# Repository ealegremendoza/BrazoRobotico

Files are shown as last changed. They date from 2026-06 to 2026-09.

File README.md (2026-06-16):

# Brazo robótico programable mediante ROS para automatización de tareas repetitivas basado en grabación y reproducción de trayectorias

Proyecto Final de Ingeniería Electrónica orientado al desarrollo de un brazo robótico de bajo costo para automatización de tareas repetitivas mediante grabación y reproducción de trayectorias.

El proyecto propone construir un manipulador robótico capaz de ser movido manualmente por el usuario, registrar una trayectoria y luego reproducirla de forma automática con precisión y repetibilidad. La solución se basa en ROS 2 para la lógica de control, cinemática, planificación de movimientos y futura integración con simulación en Gazebo.

## Objetivo general

Diseñar e implementar un brazo robótico programable que permita automatizar tareas simples de manipulación de objetos mediante un esquema de programación por demostración, evitando que el usuario tenga que escribir código para enseñarle una secuencia de movimientos al robot.

## Idea de funcionamiento

1. El usuario coloca el brazo en modo grabación.
2. El usuario mueve manualmente el brazo hasta las posiciones deseadas.
3. El sistema registra la trayectoria realizada.
4. El usuario selecciona una trayectoria guardada desde la interfaz física.
5. El brazo reproduce automáticamente la secuencia de movimientos.

## Alcance del proyecto

El entregable inicial contempla:

- Brazo robótico de 5 grados de libertad más pinza.
- Movimiento de objetos pequeños y livianos.
- Grabación, reproducción y borrado de trayectorias.
- Interfaz física simple mediante display y botones.
- Control de servomotores desde una computadora integrada compatible con ROS 2.
- Simulación del brazo en Gazebo para validar movimientos antes de la implementación física.
- Fabricación mediante piezas impresas en 3D, tomando como referencia el diseño SO-ARM100/SO-ARM101.

Quedan fuera del alcance inicial:

- Visión artificial.
- Detección de objetos por cámara.
- Algoritmos de inteligencia artificial.
- Navegación autónoma.
- Aplicación de escritorio para control remoto del brazo.
- Control por voz o interfaz conversacional.

## Aplicaciones previstas

El sistema está pensado para automatización ligera en entornos industriales, educativos o de laboratorio. Algunos casos de uso posibles son:

- Operaciones de pick-and-place de objetos livianos.
- Movimiento repetitivo de piezas entre posiciones predefinidas.
- Estaciones de testing electrónico.
- Demostraciones educativas de robótica, ROS 2 y cinemática de manipuladores.
- Prototipos de automatización para PyMEs donde un robot industrial de alta gama no resulta justificable.

## Arquitectura conceptual

El sistema se organiza en los siguientes bloques principales:

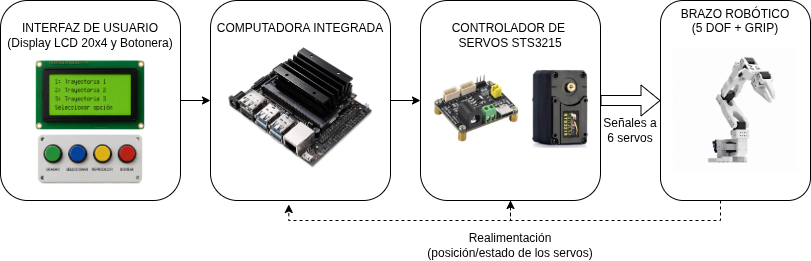
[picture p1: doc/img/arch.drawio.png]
Diagrama en bloques


## Hardware previsto

| Componente | Descripción |
|---|---|
| Brazo robótico | Basado en el proyecto SO-ARM100/SO-ARM101. |
| Estructura | Piezas impresas en 3D. Prototipado en PLA y posible versión final en PETG. |
| Actuadores | 6 servomotores STS3215: 5 DOF + pinza. |
| Controlador de servos | Placa driver compatible con servomotores STS3215. |
| Computadora integrada | A definir. Debe ser compatible con ROS 2. |
| Interfaz de usuario | Display LCD y botonera física. |
| Alimentación | A definir según consumo final de servos, computadora integrada e interfaz. |

## Software previsto

| Módulo | Función |
|---|---|
| ROS 2 | Framework principal para control y comunicación entre nodos. |
| Nodo de control del brazo | Envío de comandos hacia el controlador de servomotores. |
| Nodo de lectura de estado | Lectura de posición/estado de cada servomotor. |
| Nodo de grabación | Registro de trayectorias generadas por el usuario. |
| Nodo de reproducción | Ejecución automática de trayectorias guardadas. |
| Nodo de interfaz | Gestión de botones, display y estados del sistema. |
| Simulación Gazebo | Validación virtual del modelo y de los movimientos. |

## Requisitos funcionales principales

El brazo robótico deberá ser capaz de:

- Agarrar, levantar, sostener y trasladar objetos pequeños y livianos.
- Mover objetos desde una zona predefinida hacia otra zona predefinida.
- Permitir el encendido y apagado seguro del sistema.
- Permitir el movimiento manual del brazo durante el modo de grabación.
- Guardar trayectorias realizadas por el usuario.
- Borrar trayectorias previamente almacenadas.
- Reproducir trayectorias guardadas.
- Informar el estado del sistema mediante una interfaz simple.

## Estado actual del repositorio

Actualmente el repositorio contiene principalmente documentación del proyecto:

```text
BrazoRobotico/
└── doc/
    ├── img/          # Imágenes y diagramas del proyecto
    ├── md/           # Documentación en Markdown
    ├── pdf/          # Documentos exportados en PDF
    └── tables/       # Planillas de gestión y trazabilidad
    └── datasheets/   # Hojas de datos  
```

Archivos Markdown principales:

| Archivo | Contenido |
|---|---|
| `doc/md/agent.md` | Índice general de la documentación del proyecto. |
| `doc/md/fundamentos.md` | Idea base, alcance, motivación y funcionamiento esperado. |
| `doc/md/propuesta.md` | Propuesta aprobada por la cátedra. |
| `doc/md/proyecto-objetivos-v3.md` | Desarrollo ampliado de objetivos y alcance. |
| `doc/md/requisitos.md` | Requisitos funcionales y técnicos. |
| `doc/md/referencias.md` | Referencias de proyectos similares y brazo elegido. |
| `doc/md/materiales.md` | Materiales y componentes considerados. |
| `doc/md/modelos.md` | Modelos 3D evaluados. |
| `doc/md/cursos.md` | Recursos de aprendizaje relacionados con modelado 3D. |
| `doc/md/links.md` | Links útiles, tablero de seguimiento y bitácora. |
| `doc/md/respaldo.md` | Documento de respaldo con descripción general, FODA y desafío tecnológico. |
| `doc/md/tareas.md` | Listado de tareas tareas del proyecto. |

## Próximos pasos

- Definir computadora integrada compatible con ROS 2.
- Definir controlador de servomotores STS3215.
- Definir display, botonera y esquema de interacción con el usuario.
- Incorporar el modelo URDF/Xacro del brazo.
- Crear simulación en Gazebo.
- Implementar nodos ROS 2 para lectura de servos, grabación y reproducción de trayectorias.
- Validar el comportamiento primero en simulación y luego en el prototipo físico.
- Documentar procedimiento de instalación, calibración y operación.

## Roadmap tentativo

| Etapa | Descripción | Estado |
|---|---|---|
| Documentación inicial | Propuesta, fundamentos, requisitos y referencias. | En desarrollo |
| Selección de hardware | Servos, controlador, computadora integrada, display y fuente. | Pendiente |
| Simulación | Modelo del brazo en ROS 2/Gazebo. | Pendiente |
| Control básico | Movimiento de articulaciones desde ROS 2. | Pendiente |
| Grabación de trayectorias | Registro de posiciones y tiempos. | Pendiente |
| Reproducción automática | Ejecución de trayectorias guardadas. | Pendiente |
| Modelo mecánico | Adaptación e impresión 3D del brazo. | Pendiente |
| Integración final | Hardware, software e interfaz física. | Pendiente |

## Licencia

A definir.

## Autor
- Alumno: Ezequiel Alegre Mendoza 
- Tutores: Ing. Fernando Fiamberti, Ing. Claudia Orlandi
- Docente: Ing. Silvio Tapino
- Proyecto Final - Ingeniería Electrónica

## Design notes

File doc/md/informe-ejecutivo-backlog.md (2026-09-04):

# Informe Ejecutivo — Avance del Backlog

**Proyecto:** BrazoRobotico (brazo SO-ARM101, control ESP32 + simulación ROS2/Gazebo)
**Fecha del informe:** 2026-09-04 (primer informe)
**Fuente:** `doc/md/BACKLOG.md` y bitácoras individuales por tarea (`doc/md/bitacora-*.md`)

## Resumen general

| Categoría | Completadas | Pendientes | Total |
|---|---|---|---|
| 🔧 ESP32 / Embedded Systems | 3 (E01, E02, E05) | 5 (E03, E04, E06, E07, E08) | 8 |
| 🦾 Brazo Robótico | 2 (R01, R02) | 1 (R03) | 3 |
| **Total** | **5** | **6** | **11** |

**Avance global: 5 de 11 tareas (~45%)**, distribuidas en dos frentes independientes: comunicación serie ESP32↔Arduino (hardware/firmware) y simulación del brazo en Gazebo/ROS2 (software). Ambos frentes tienen su primera integración end-to-end funcionando.

---

## 🔧 ESP32 / Embedded Systems

### ✅ E01 — UART TX-RX en el ESP32
Implementado y validado un loopback UART2 (TX↔RX puenteados) sobre ESP-IDF/FreeRTOS en `firmware/uart_test/`. Se confirmó a nivel esquemático el módulo (ESP32-WROOM-32UE) y la elección de pines (UART2, evitando UART0 reservada para programación/monitor y UART1 por conflicto con la flash SPI). Señal validada físicamente con analizador lógico. Configuración de pines migrada de `#define` a Kconfig (`idf.py menuconfig`), quedando parametrizable sin recompilar código.

### ✅ E02 — Medición de niveles TX/RX del ESP32
Medidos los niveles lógicos reales de un GPIO de salida del ESP32 con multímetro: **0.00V (LOW) / 3.29V (HIGH)**, confirmando lógica CMOS estándar de 3.3V. Este dato fue el insumo directo para decidir en E05 que hacía falta un conversor de nivel lógico hacia el Arduino Nano (5V).

### ✅ E05 — Comunicación ESP32 ↔ Arduino Nano vía HW-221
Tarea más extensa del frente embedded. Resultado: **comunicación bidireccional validada end-to-end** — PC (monitor serie del ESP32) → ESP32 → conversor de nivel HW-221 (TXS0108E) → Arduino Nano → LED, con protocolo de framing propio (STX/FS/ETX/LRC) y ACK de vuelta por el mismo camino. Comandos "ON"/"OFF" funcionando de forma confiable en ambas direcciones.

Puntos clave resueltos en el camino:
- Identificación del chip HW-221 (marcado YF08E = TXS0108E de Texas Instruments) y su datasheet.
- Diseño y cableado del circuito completo (ver diagrama en la bitácora).
- Protocolo de framing STX/FS/ETX/LRC, reutilizable para comandos multi-campo futuros (control de servos).
- Varios bugs de firmware corregidos: máquina de estados que nunca ejecutaba su estado final, `stdin` no bloqueante del ESP32 partiendo comandos en fragmentos, lectura UART que no esperaba una línea completa.
- Un problema físico (cable TX del Nano desconectado) diagnosticado por asimetría en el comportamiento (una dirección funcionaba, la otra no).

### ⏳ Pendientes — E03, E04, E06, E07, E08
No iniciadas. Encadenadas: E03 (adaptador lógico hacia el driver de motores) y E04 (protocolo de comando del driver) habilitan E06 (traducción de comandos PC→driver en el ESP32); E07/E08 son una decisión de arquitectura (desacoplar la gestión del driver hacia el ESP32) todavía sin resolver.

---

## 🦾 Brazo Robótico

### ✅ R01 — Investigación de URDF disponible
Confirmado que el repositorio base (`TheRobotStudio/SO-ARM100`) sí provee URDF (SO100 y SO101, dos calibraciones), aunque sin paquete ROS2/Gazebo armado — solo geometría + mallas. Se vendorizó el URDF de SO101 (calibración nueva) al repo en `ros2/urdf/so101/`, quedando como base de trabajo para R02.

### ✅ R02 — Brazo funcionando en simulación Gazebo/ROS2
Tarea de mayor alcance del proyecto hasta ahora. Se armó desde cero el workspace ROS2 (`robotic_arm_ws/`) con dos paquetes:

- **`robotic_arm_description`**: URDF/xacro completo del brazo (9 links + 8 joints, límites de calibración reales), integración con `ros2_control` (`<ros2_control>` + plugin `gz_ros2_control`), launch files para visualizar en RViz y para spawnear en Gazebo Sim (Harmonic).
- **`robotic_arm_controller`**: configuración de controladores (`joint_state_broadcaster`, `arm_controller`, `gripper_controller` sobre `JointTrajectoryController`), launch para activarlos, y un nodo de control interactivo por sliders (`slider_control.py`) para mover el brazo en vivo desde una GUI.

**Resultado validado end-to-end:** el brazo se visualiza correctamente en RViz y Gazebo, `ros2_control` se activa sin errores, y se comandó y ejecutó exitosamente una trayectoria real (`Goal successfully reached!`) — el brazo responde a comandos ROS2 en simulación.

Pendiente no bloqueante: la geometría de `<collision>` usa las mismas mallas STL de detalle completo que el `<visual>`, y el motor de física de Gazebo (`dartsim`) no soporta construir colisión desde malla — confirmado con evidencia directa (log propio) y cruzado contra el proyecto de referencia del curso (mismo problema, limitación general de `dartsim`, no específica de este proyecto). El brazo hoy no tiene colisión física real en ningún link; para física realista (agarre de objetos, contacto con superficies) hace falta reemplazar esa geometría por formas primitivas (cajas/cilindros).

### ⏳ Pendiente — R03
Definir los nodos ROS2 que van a manejar el brazo robótico real (no solo simulado), basándose en el curso de referencia. Depende conceptualmente de lo armado en R02 (misma estructura de controladores aplicaría al hardware real).

---

## Próximos pasos sugeridos

1. **Frente embedded:** definir E03/E04 (adaptador lógico + protocolo del driver de motores) para desbloquear E06.
2. **Frente robótica:** R03 (nodos de control real) y, en paralelo, resolver la geometría de colisión de R02 si se necesita física realista antes de avanzar a manipulación de objetos.
3. Evaluar si conviene una tarea nueva que conecte ambos frentes (el driver de motores real controlado desde los mismos nodos ROS2 que hoy mueven la simulación).

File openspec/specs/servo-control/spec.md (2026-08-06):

# Servo Control

## Purpose

Control a 6-DOF robotic arm built with Feetech STS3215 bus servos (IDs 1-6)
from a workstation over a USB serial port (`/dev/ttyACM0`), using a desktop
GUI for commanding target positions and observing live feedback.

## Requirements

### REQ-SERVO-001: Connection lifecycle
The application opens the bus at the user-provided device path with a
baudrate of 1000000 (the STS3215 factory default), and exposes Connect and
Disconnect actions that are mutually exclusive. While disconnected, all
servo controls are disabled.

#### Scenario: Connect to the bus
- **Given** servos 1 and 2 are powered and on the bus at `/dev/ttyACM0`
- **When** the user enters `/dev/ttyACM0` and clicks Connect
- **Then** the port opens, the baudrate is set to 1000000, and per-servo
  status is polled every 100 ms
- **And** Connect becomes disabled while Disconnect becomes enabled

#### Scenario: Disconnect
- **When** the user clicks Disconnect while connected
- **Then** the port is closed, all sliders are disabled, and all servos are
  shown as disconnected

### REQ-SERVO-002: Per-servo command with limits
Each servo has one horizontal slider and Min/Max inputs beside it. Changing
Min/Max re-ranges that slider, clamped to the servo's native 0-4095 count
range (12-bit position). A centered label above the slider shows the current
commanded position.

#### Scenario: Re-range a slider
- **Given** the slider of servo 1 ranges from 0 to 4095
- **When** the user sets Min=1000 and Max=2000
- **Then** the slider re-ranges to 1000-2000 and any out-of-range current
  value is clamped into the new range

### REQ-SERVO-003: Per-servo status from sync read
Servo connectivity and feedback are derived per servo from
`GroupSyncRead.isAvailable(id, ...)`, never from the global
`txRxPacket()` result, which reports `COMM_RX_CORRUPT` whenever any id in
the group is missing.

#### Scenario: Only two of six servos connected
- **Given** only servos 1 and 2 are on the bus
- **When** a sync read cycle completes
- **Then** servos 1 and 2 are marked Connected with live position and
  velocity feedback and enabled sliders
- **And** servos 3-6 are marked Disconnected with disabled sliders

### REQ-SERVO-004: Feedback display
To the right of each slider the UI shows the read position (raw counts), the
read velocity (signed via `scs_tohost(value, 15)`), and the
connected/disconnected state, color-coded.

### REQ-SERVO-005: Write behaviour
Slider movement writes the goal position with debounce (40 ms coalescing)
plus an immediate flush on mouse release, using `WritePosEx(id, position,
speed=2400, acc=50)`. The write is skipped for a servo whose last poll
marked it disconnected.

## Design

- **GUI**: tkinter/ttk single-window, one `ServoRow` frame per servo.
- **Bus reads**: one `GroupSyncRead(packetHandler, SMS_STS_PRESENT_POSITION_L, 4)`
  covers position (56-57) and speed (58-59) for all six ids in a single
  transaction; `scs_tohost(speed_raw, 15)` restores the sign.
- **Bus writes**: single-servo `WritePosEx` per changed slider.
- **Polling**: a 100 ms `after()` loop drives feedback; a failed serial
  operation triggers disconnect instead of crashing the UI.
- **Errors**: SDK failures are `COMM_*` return codes, never exceptions; the
  UI surfaces connect/open failures as a status label.
- **Entry point**: `STServo_Python/servo_control_ui.py` adds
  `stservo-env/` to `sys.path` so `scservo_sdk` imports from any cwd.

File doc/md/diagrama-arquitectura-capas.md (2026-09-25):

# Arquitectura por capas

```mermaid
flowchart TB
    subgraph L7[7 - Aplicacion]
        SUP[arm_supervisor]
        REC[recording_manager]
        TS[task_server]
        UI[RViz / consola Linux - opcional]
    end

    subgraph L6[6 - Planificacion de movimiento - MoveIt2]
        MG[move_group]
        MPY[MoveItPy]
    end

    subgraph L5[5 - Control - ros2_control]
        JTC[arm_controller y gripper_controller]
        JSB[joint_state_broadcaster]
        RSP[robot_state_publisher]
    end

    subgraph L4[4 - Interfaz de hardware]
        PLUGIN[RoboticArmInterface - plugin C++]
    end

    subgraph L3[3 - Comunicacion]
        UART[UART 115200 - tramas M, E, S, D]
    end

    subgraph L2[2 - Firmware ESP32]
        FW[Estados, parada de emergencia, torque, display]
    end

    subgraph L1[1 - Hardware]
        SERVOS[Servos STS3215]
        PANEL[Botonera, LCD 20x4, potenciometro]
    end

    TS --> MPY
    UI --> MG
    MG --> JTC
    MPY --> JTC
    JTC --> PLUGIN
    PLUGIN --> UART
    UART --> FW
    FW --> SERVOS
    FW --> PANEL
```

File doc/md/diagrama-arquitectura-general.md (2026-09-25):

# Arquitectura general

```mermaid
flowchart TB
    USER([Usuario])

    subgraph HW[Brazo robotico]
        PANEL[Botonera, LCD y potenciometro]
        ESP[ESP32 - seguridad y control de servos]
        SERVOS[Servos STS3215]
    end

    subgraph PC[Computadora integrada - ROS 2]
        APP[Aplicacion - supervisor, grabaciones y tareas]
        MOTION[Planificacion de movimiento - MoveIt2]
        CTRL[Control - ros2_control]
    end

    USER --> PANEL
    USER -.->|opcional| APP
    PANEL --> ESP
    ESP --> SERVOS
    ESP -->|UART - protocolo propio| CTRL
    CTRL --> ESP
    CTRL -->|eventos de botones| APP
    APP --> MOTION
    MOTION --> CTRL
```

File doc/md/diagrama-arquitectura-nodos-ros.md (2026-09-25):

# Nodos, topics, actions y servicios ROS 2

```mermaid
flowchart LR
    subgraph CM[controller_manager]
        PLUGIN[RoboticArmInterface - hardware plugin]
        JSB[joint_state_broadcaster]
        ARM[arm_controller]
        GRIP[gripper_controller]
    end
    RSP[robot_state_publisher]
    MG[move_group]
    RVIZ[rviz2 - opcional use_rviz]
    TS[task_server - MoveItPy]
    SUP[arm_supervisor]
    REC[recording_manager]
    ESP[ESP32 - UART M E S D]

    T_JS(["/joint_states"])
    T_RD(["/robot_description"])
    T_TF(["/tf"])
    T_EV(["/esp32/events"])
    T_ST(["/esp32/start"])
    T_DI(["/esp32/display"])
    T_SS(["/arm_supervisor/state"])

    A_ARM[["/arm_controller/follow_joint_trajectory"]]
    A_GRIP[["/gripper_controller/follow_joint_trajectory"]]
    A_MOVE[["/move_action"]]
    A_TASK[["/task_server"]]

    S_REC{{"save, list, get, delete"}}

    ESP -->|serial| PLUGIN
    PLUGIN -->|serial| ESP

    JSB --> T_JS
    T_JS --> RSP
    T_JS --> MG
    T_JS --> TS
    RSP --> T_RD
    RSP --> T_TF
    T_TF --> RVIZ

    RVIZ --> A_MOVE
    A_MOVE --> MG
    MG --> A_ARM
    MG --> A_GRIP
    TS --> A_ARM
    TS --> A_GRIP
    A_ARM --> ARM
    A_GRIP --> GRIP

    PLUGIN -.-> T_EV
    T_EV -.-> SUP
    SUP -.-> T_ST
    T_ST -.-> PLUGIN
    SUP -.-> T_DI
    T_DI -.-> PLUGIN
    SUP -.-> T_SS
    T_SS -.-> TS

    SUP -.->|home, ejecutar grabacion| A_TASK
    A_TASK --> TS
    SUP -.->|cancelar ante parada| A_ARM
    SUP -.-> S_REC
    S_REC -.-> REC

    classDef planned stroke-dasharray: 5 5
    class SUP,REC,T_EV,T_ST,T_DI,T_SS,S_REC planned
```

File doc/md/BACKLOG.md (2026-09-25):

# Backlog de Tareas

_Última actualización: 2026-09-25_

## Cómo usar este documento
- Agregar tareas nuevas bajo la categoría correspondiente (o crear una nueva sección si hace falta).
- Marcar como hecha cambiando `[ ]` por `[x]`.
- Mover tareas completadas a la sección "Hecho" si querés mantener el backlog activo limpio.

---

## 🔧 ESP32 / Embedded Systems

- [x] **[E01]** Programar ESP32 para poder enviar y recibir mensajes por puerto serie a través de los pines TX-RX
- [x] **[E02]** Medir niveles de las señales que salen por TX y RX del ESP32 usando el analizador lógico
- [x] **[E03]** Averiguar si es necesario un adaptador lógico entre el ESP32 y el driver de los servomotores; si se necesita, conseguir uno — ver `doc/md/bitacora-E03-adaptador-logico.md` (no hace falta, ambos son 3.3V)
- [x] **[E04]** Averiguar cómo comandar el driver de motores vía TX-RX — ver `doc/md/bitacora-E04-protocolo-driver.md` (protocolo Feetech/Dynamixel-like, header 0xFF 0xFF + ID + length + instrucción + parámetros + checksum)
- [x] **[E05]** Probar el código del ESP32 para manejar TX-RX con un Arduino Nano; programar el Arduino Nano para que pueda enviar y recibir mensajes por los pines TX-RX
- [ ] **[E06]** (Depende de E01) Hacer un código en el ESP32 que traduzca los comandos recibidos de la computadora principal en los comandos que precisa el driver de los motores; estudiar el código Python de ejemplo
- [ ] **[E07]** Evaluar si hace falta realmente desacoplar la gestión del driver de motores hacia el ESP32, o si está bien como está
- [ ] **[E08]** (Depende de E07) Hacer un nuevo script de Python para delegar la parte de gestión del driver de motores al ESP32

## 🦾 Brazo Robótico

- [x] **[R01]** Averiguar si el proyecto armso-101 (en el cual está basado mi proyecto) tiene un URDF para simular con Gazebo ROS2 — ver `doc/md/bitacora-R01-urdf.md`
- [x] **[R02]** (Depende de R01) Si tiene URDF: tratar de levantar el modelo en Gazebo. Si no tiene: ver cómo generarlo usando los STL disponibles — ver `doc/md/bitacora-R02-gazebo.md`. Pendiente no bloqueante: geometría de `<collision>` (STL → primitivas, `dartsim` no soporta colisión desde malla)
- [ ] **[R03]** Definir la arquitectura ROS2 de la aplicación: paquetes, nodos, interfaces entre ellos (topics, servicios, actions) y diferencias entre simulación y robot real, tomando como base el curso de manipuladores con ROS2
- [ ] **[R04]** Investigar/implementar mitigación de backlash mecánico de los servos STS3215 (compensación por software al invertir dirección, ya que el encoder está en el eje del motor y no en el eslabón de salida)
- [x] **[R05]** Implementar MoveIt2 para planificación de movimiento del brazo — referencia: `/home/ezequiel/cursos/Robotics-and-ROS2-Manipulators/Robotics-and-ROS-2-Learn-by-Doing-Manipulators/Section6_Kinematics/arduinobot_ws` — ver `doc/md/bitacora-R05-moveit2.md`. Plan & Execute verificado end-to-end en Gazebo (grupos `arm` y `gripper`)
- [x] **[R06]** Aprender el manejo de Actions en ROS2 (goal/result/feedback, action server y client, patrón Future) — referencia: ejemplo Fibonacci en `/home/ezequiel/cursos/Robotics-and-ROS2-Manipulators/Robotics-and-ROS-2-Learn-by-Doing-Manipulators/Section7_Application/arduinobot_ws` — ver `doc/md/bitacora-R06-actions.md`
- [x] **[R07]** (Depende de R05, R06) Implementar API para manejar MoveIt2 (interfaz programática para enviar goals de planificación/ejecución al brazo, en vez de operarlo solo desde RViz) — ver `doc/md/bitacora-R07-moveit-api.md`. `task_server` verificado end-to-end en Gazebo (tareas 0-6)
- [ ] **[R08]** (Depende de R07) Ejecutar el `task_server`/API de MoveIt2 sobre el brazo real — recalibrar o verificar que el "0" físico de los servos coincida con el "0" del modelo URDF antes de correr goals planificados en hardware
- [ ] **[R09]** (Depende de R05) Implementar en C++ el plugin `ros2_control` (`hardware_interface::SystemInterface`) para el brazo real — comunicación directa por puerto serie reusando la lógica de `STServo_Python`, dejando la interfaz reemplazable más adelante por una variante con ESP32 (ver `[E07]`)
- [x] **[R10]** Crear los nodos `simple_serial_transmitter` y `simple_serial_receiver` en Python (topic ↔ puerto serie) igual que en el curso — referencia: `/home/ezequiel/cursos/Robotics-and-ROS2-Manipulators/Robotics-and-ROS-2-Learn-by-Doing-Manipulators/Section9_Build/arduinobot_ws/src/arduinobot_firmware/arduinobot_firmware` — ver `doc/md/bitacora-R10-serial-nodes.md`
- [x] **[R11]** Estudiar cómo funciona un lifecycle node (managed node) en ROS2 — ver `doc/md/bitacora-R11-lifecycle-node.md`
- [x] **[R12]** Crear el paquete `robotic_arm_bringup` con `simulated_robot.launch.py` y `real_robot.launch.py`, que incluyan los launch de description (solo sim), controller, moveit y remote pasándoles `is_sim` — referencia: `/home/ezequiel/cursos/Robotics-and-ROS2-Manipulators/Robotics-and-ROS-2-Learn-by-Doing-Manipulators/Section9_Build/arduinobot_ws/src/arduinobot_bringup` — ver `doc/md/bitacora-R12-bringup.md`. Simulado verificado end-to-end (RViz + `task_server`); `real_robot.launch.py` sin probar hasta `[E06]`

## 📌 Otros

- [ ] (agregar tareas aquí)

---

## ✅ Hecho

- [x] (ejemplo de tarea completada)

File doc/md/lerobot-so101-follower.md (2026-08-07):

# LeRobot — Brazo SO-101 Follower: control y calibración

Documento de profundización técnica sobre el subsistema *follower* del brazo SO-101 en
LeRobot (HuggingFace), enfocado en su **control** y su **calibración**. Todo el contenido
fue verificado contra el código fuente del repositorio local de LeRobot (rutas listadas en
[Referencias](#7-referencias)); cuando un dato no pudo confirmarse se indica explícitamente.

---

## 1. Resumen y contexto

LeRobot es el framework de código abierto de HuggingFace para *robot learning*: unifica
grabación de demostraciones, entrenamiento de políticas y teleoperación sobre hardware real.
Su ecosistema de brazos de bajo costo (diseñados por TheRobotStudio, familias SO-ARM100 /
SO-ARM101) incluye el brazo **SO-101**, usado como brazos *leader* (guía) y *follower*
(ejecutor).

El brazo **SO-101 follower** tiene 5 grados de libertad más una pinza (gripper). Los 6 ejes
usan servos **Feetech STS3215** con reductora 1/345 y resolución de encoder de 12 bits
(4096 cuentas por vuelta). El *leader* del SO-101 usa en cambio motorizaciones mixtas
(1/191, 1/345, 1/147 según el eje) para poder sostenerse y moverse a mano.

Para el proyecto **BrazoRobotico** (ROS 2 + grabación/reproducción de trayectorias sobre
servos Feetech ST) este subsistema es la referencia de cómo LeRobot resuelve los problemas
reales de un brazo de bajo costo:

- **Calibración**: encontrar el cero físico (`homing_offset`), el rango mecánico
  (`range_min`/`range_max`) y persistirlo de forma consistente.
- **Control**: un bucle de teleoperación pasivo que lee posiciones, normaliza valores y
  escribe objetivos de posición con protecciones de seguridad (clip de acción, límites de
  torque en la pinza).

---

## 2. Arquitectura del subsistema

La clase base es `SOFollower(Robot)` en
`src/lerobot/robots/so_follower/so_follower.py` (242 líneas):

```python
class SOFollower(Robot):
    config_class = SOFollowerRobotConfig
    name = "so_follower"
```

- **Alias `SO100Follower` y `SO101Follower`**: ambos son la misma clase
  (`SO100Follower = SOFollower` y `SO101Follower = SOFollower` al final del archivo). La
  distinción entre SO-100 y SO-101 es solo cosmética desde el punto de vista del código.
- **Registro de configuración**: `SOFollowerRobotConfig` se registra con dos claves mediante
  `@RobotConfig.register_subclass`:
  - `"so101_follower"`
  - `"so100_follower"`
  - El atributo `name` de la instancia queda en `"so_follower"` (sin versión), lo cual
    condiciona la ruta del archivo de calibración (ver [Ruta del JSON](#42-ruta-del-json-y-estructura)).
- **Factory**: `make_robot_from_config(config)` en `src/lerobot/robots/utils.py` despacha
  `"so100_follower"` → `SO100Follower` y `"so101_follower"` → `SO101Follower`. En
  `__init__` el bus se arma con 6 motores `sts3215`:

  | Nombre | ID | Modo de normalización |
  | ------ | -- | --------------------- |
  | `shoulder_pan` | 1 | `DEGREES` (o `RANGE_M100_100` si `use_degrees=False`) |
  | `shoulder_lift` | 2 | ídem |
  | `elbow_flex` | 3 | ídem |
  | `wrist_flex` | 4 | ídem |
  | `wrist_roll` | 5 | ídem |
  | `gripper` | 6 | `RANGE_0_100` (siempre) |

- **Bimanual**: `BiSOFollower` (`src/lerobot/robots/bi_so_follower/bi_so_follower.py`)
  compone dos instancias de `SOFollower` (`left_arm`/`right_arm`), registrado como
  `"bi_so_follower"`. Cada brazo mantiene su propio bus, puerto y calibración.

---

## 3. Control del brazo follower

### 3.1 Ciclo de vida

El flujo típico (usado por los scripts y por el contexto manager `with robot:`):

```
connect()  →  calibrate() (si aplica)  →  configure()
→  get_observation() / send_action()  (bucle)
→  disconnect()
```

Detalles de cada etapa:

- `connect(calibrate=True)` (so_follower.py:92):
  1. `bus.connect()` → abre el puerto serie y hace el *handshake* (ver [Protocolo Feetech](#38-protocolo-feetech)).
  2. Si `not is_calibrated and calibrate`: invoca `calibrate()` (recalibración interactiva o
     reescritura desde archivo, ver [Calibración](#4-calibración-en-profundidad)).
  3. Conecta las cámaras.
  4. Llama `configure()`.
  - El docstring advierte: se asume que en el momento de conectar **el brazo está en
    reposo** (posición de reposo), porque el torque puede deshabilitarse de forma segura
    para correr la calibración.
- `get_observation()` → `sync_read` de `Present_Position` + captura de cámaras.
- `send_action(action)` → escribe `Goal_Position` por `sync_write` con clip de seguridad.
- `disconnect()` → `bus.disconnect(disable_torque_on_disconnect)` + desconexión de cámaras.
  Si `disable_torque_on_disconnect=True` (valor por defecto), se deshabilita el torque antes
  de cerrar el puerto para evitar que los motores queden aplicando torque de resistencia.

`Robot` (`src/lerobot/robots/robot.py`) aporta la infraestructura base: `_load_calibration`
/ `_save_calibration`, `calibration_dir`, `calibration_fpath` y el context manager
(`__enter__` conecta, `__exit__` desconecta incluso con error). También define las
propiedades abstractas `observation_features` y `action_features` que describen la estructura
plana de observaciones/acciones: claves `"<motor>.pos"` y, para las cámaras, la clave de
cámara (más `"<cam>_depth"` si usa profundidad).

### 3.2 Configuración clave

`SOFollowerConfig` (`config_so_follower.py`, 64 líneas) — hereda de `RobotConfig` (que
aporta `id`, `calibration_dir`):

| Campo | Valor por defecto | Significado |
| ----- | --- | --- |
| `port` | — (obligatorio) | Puerto serie del bus (p. ej. `/dev/ttyACM0`) |
| `disable_torque_on_disconnect` | `True` | Deshabilita torque al desconectar |
| `max_relative_target` | `None` | Límite máximo de la acción relativa; `float` (todos los motores) o `dict[str, float]` por motor |
| `cameras` | `{}` | Configuración de cámaras (`CameraConfig`) |
| `use_degrees` | `True` | `True` → normalización `DEGREES`; `False` → `RANGE_M100_100` |
| `position_p_coefficient` | `16` | Ganancia P del PID de posición |
| `position_i_coefficient` | `0` | Ganancia I |
| `position_d_coefficient` | `32` | Ganancia D |
| `num_read_retries` | `2` | Reintentos adicionales de `sync_read` ante paquetes corruptos |

`SOFollowerRobotConfig` es la unión de `RobotConfig` + `SOFollowerConfig` (sin campos
adicionales), con los alias `SO100FollowerConfig`/`SO101FollowerConfig`.

### 3.3 Normalización de valores

El bus normaliza automáticamente los registros `Goal_Position` y `Present_Position`
(única lista `NORMALIZED_DATA = ["Goal_Position", "Present_Position"]` en feetech.py:47).
La normalización exige calibración cargada: sin `calibration`, `_normalize`/`_unnormalize`
lanzan `RuntimeError`.

El modo de normalización se define por motor en el `MotorNormMode`
(`src/lerobot/motors/motors_bus.py:169`):

- **`DEGREES`** (cuerpo, cuando `use_degrees=True`). Lectura normalizada:

  ```
  mid   = (range_min + range_max) / 2
  max_res = resolution - 1          # = 4095 para STS3215
  norm  = (raw - mid) * 360 / max_res
  ```

  Es decir, la posición central (`mid`) reporta `0°` y el rango mecánico completo abarca
  ±180°. La escritura inversa es `raw = int(val * max_res / 360 + mid)`.

- **`RANGE_0_100`** (pinza). Normaliza a porcentaje:

  ```
  norm = ((raw - range_min) / (range_max - range_min)) * 100
  ```

  Para la pinza, **`100` = abierta** (en `range_max`) y `0` = cerrada (en `range_min`). Con
  `drive_mode=1` se invierte (`norm = 100 - norm`).

- **`RANGE_M100_100`** (cuerpo cuando `use_degrees=False`): normaliza al rango [-100, 100]
  con `norm = ((raw - min) / (max - min)) * 200 - 100`, negando el signo si `drive_mode=1`.

  > Detalle: `DEGREES` **ignora** `drive_mode`; los modos `RANGE_*` sí lo aplican. En la
  > calibración del follower siempre se escribe `drive_mode=0`, por lo que la inversión
  > solo es relevante si un JSON trae `drive_mode=1` (caso típico de brazos *leader* con
  > ejes montados invertidos).

Los valores crudos leídos/escritos se convierten siempre al espacio normalizado cuando el
registro está en `NORMALIZED_DATA`, tanto en `sync_read`/`sync_write` como en `read`/`write`
(con el flag `normalize`).

### 3.4 `configure()`

`SOFollower.configure()` (so_follower.py:159) se ejecuta bajo el context manager
`bus.torque_disabled()` (garantiza re-habilitar torque al final):

1. `bus.configure_motors()` (feetech.py:209), para cada motor:
   - `Return_Delay_Time = 0` (reduce el retardo de respuesta de los 500 µs por defecto al
     mínimo de 2 µs).
   - `Maximum_Acceleration = 254` y `Acceleration = 254` (solo protocolo 0 para el primero)
     para acelerar el arranque y frenado.
   - **Limpieza del bit 4 (0x10) del registro `Phase` (0x12)** en los `sts3215`: fuerza el
     modo de realimentación de ángulo a 0, manteniendo las lecturas en `[0, resolution-1]`
     y evitando valores negativos o desbordados.
2. Por motor:
   - `Operating_Mode = OperatingMode.POSITION.value` (= 0, modo servo de posición).
   - `P_Coefficient = 16`, `I_Coefficient = 0`, `D_Coefficient = 32` (desde config).
3. **Límites de seguridad de la pinza** (`gripper`), para evitar quemar el motor:
   - `Max_Torque_Limit = 500` (50 % del torque máximo).
   - `Protection_Current = 250` (50 % de la corriente máxima).
   - `Overload_Torque = 25` (25 % de torque al detectar sobrecarga).

### 3.5 `send_action()`

`SOFollower.send_action(action)` (so_follower.py:204) devuelve **la acción realmente
enviada** (posiblemente recortada), que puede diferir de la original:

1. Extrae de `action` las claves que terminan en `.pos` como `goal_pos` por motor.
2. **Clip por `max_relative_target`**: si está configurado, primero hace un
   `sync_read("Present_Position")` adicional y luego
   `ensure_safe_goal_position(goal_present_pos, max_relative_target)`
   (`src/lerobot/robots/utils.py:91`), que recorta el delta `goal - present` al rango
   `[±max_relative_target]` por motor. El propio código advierte: `Slower fps expected due
   to reading from the follower.` — ese `sync_read` extra encarece el bucle.
3. Escribe `Goal_Position` en todos los motores con un único `sync_write`.
4. Devuelve el dict `{f"{motor}.pos": val}` con los valores efectivamente escritos.

### 3.6 `get_observation()`

`SOFollower.get_observation()` (so_follower.py:179):

1. `bus.sync_read("Present_Position", num_retry=config.num_read_retries)` → un
   `GroupSyncRead` de los 6 motores (valores normalizados). Se convierte a claves
   `"<motor>.pos"`.
2. Por cada cámara: `read_latest()` (RGB) y opcionalmente `read_latest_depth()` (clave
   `"<cam>_depth"`).

### 3.7 El follower es pasivo: el bucle vive en el script

`SOFollower` **no tiene** `teleop_step` ni un bucle propio: es un dispositivo pasivo
que solo responde a llamadas. El bucle de control está en
`src/lerobot/scripts/lerobot_teleoperate.py` (`teleop_loop`, fps por defecto **60**):

```python
obs = robot.get_observation()                       # 1. observación
raw_action = teleop.get_action()                    # 2. acción del teleoperador
teleop_action = teleop_action_processor((raw_action, obs))
robot_action_to_send = robot_action_processor((teleop_action, obs))
_ = robot.send_action(robot_action_to_send)         # 3. enviar al follower
```

El mismo patrón de `get_observation` → `get_action` → procesadores → `send_action` es el
que usa el pipeline de grabación de datasets. `lerobot_find_joint_limits.py` usa un bucle
idéntico (ver [CLI](#45-cli)).

### 3.8 Protocolo Feetech

Detalles del bus `FeetechMotorsBus` (`src/lerobot/motors/feetech/feetech.py`, 459 líneas) y
sus tablas (`src/lerobot/motors/feetech/tables.py`, 257 líneas):

- **Comunicación**: puerto serie USB + SDK `feetech-servo-sdk` (`scservo_sdk`, basado en el
  SDK Dynamixel), protocolo **v0**, baudrate por defecto **1 Mbaud**
  (`DEFAULT_BAUDRATE = 1_000_000`), timeout de paquete 1000 ms. En la tabla de baudrates,
  1 Mbaud corresponde al valor `0` del registro `Baud_Rate`.
- **Handshake** (`_handshake`): dos verificaciones en `connect()`:
  1. `_assert_motors_exist()`: `ping` a cada ID esperado y comprobación del número de
     modelo (`sts3215` → 777). Si falta un ID o el modelo no coincide, lanza `RuntimeError`
     con la lista de motores esperados/encontrados.
  2. `_assert_same_firmware()`: lee `Firmware_Major_Version` (addr 0) y `Firmware_Minor_Version`
     (addr 1) de todos los motores; si no son iguales, lanza `RuntimeError` indicando que hay
     que actualizar el firmware con el software de Feetech.
- **Monkeypatch `setPacketTimeout`**: el SDK publicado en PyPI tiene un bug en el cálculo
  del timeout de paquete (issue IBY2S6 de Gitee, ya corregido en el repo oficial de Feetech
  pero no publicado). LeRobot lo parchea en runtime:
  `packet_timeout = (tx_time_per_byte * packet_length) + (tx_time_per_byte * 3.0) + 50`.
- **Registro `Phase` (0x12), bit 4 (0x10)**: se limpia en `configure_motors()` para los
  `sts3215` (ver [3.4](#34-configure)); solo se sabe necesario para ese modelo.
- **Lectura/escritura en grupo**: `GroupSyncRead`/`GroupSyncWrite` del SDK para
  `sync_read`/`sync_write`; `broadcast_ping` para escaneo. Nota: `sync_write` no espera
  paquete de estado (puede perder paquetes) pero es rápido; `write` sí espera respuesta
  (más lento, para configuración).
- **Paquetes corruptos**: los buses Feetech devuelven ocasionalmente un paquete de estado
  corrupto (`"Incorrect status packet!"`), sobre todo cuando varios ejes se mueven a la vez.
  Por eso `num_read_retries` (por defecto 2) reintenta de inmediato (sin `sleep`) solo ante
  fallo; el costo de lectura en estado estable no cambia.
- **Torque**: `disable_torque()` escribe `Torque_Enable = 0` **y** `Lock = 0`;
  `enable_torque()` escribe `Torque_Enable = 1` **y** `Lock = 1`. El registro `Lock`
  (addr 55) desbloquea/bloquea el EEPROM, condición necesaria para escribir la
  calibración (ver [Calibración](#4-calibración-en-profundidad)).
- **Encoding sign-magnitude, bit 15**: los registros de posición/velocidad/carga usan
  *sign-magnitude* (bit de signo = dirección). Para STS, `Goal_Position`, `Present_Position`,
  `Goal_Velocity`, `Present_Velocity`, `Goal_Speed`, `Present_Speed` y `Present_Load` usan el
  bit de signo 15; `Homing_Offset` usa el bit 11. `encode_sign_magnitude` pone el bit de
  signo en 1 si el valor es negativo: `value = (dir << sign_bit) | magnitude`, con magnitud
  máxima `(1 << sign_bit) - 1`.
- **Resolución**: 4096 ticks por vuelta (12 bits) para `sts3215`; `max_res = 4095`.

---

## 4. Calibración en profundidad

### 4.1 Qué es la calibración

Para cada motor, `MotorCalibration` (`motors_bus.py:175`) define 5 campos:

| Campo | Descripción |
| ----- | --- |
| `id` | ID en el bus (1..6) |
| `drive_mode` | Dirección/inversión del motor (0 = normal). En el follower siempre 0 |
| `homing_offset` | Desplazamiento de cero físico. Convención Feetech: `Present_Position = Actual_Position - Homing_Offset` |
| `range_min` | Límite inferior del rango mecánico (cuentas de encoder) |
| `range_max` | Límite superior del rango mecánico |

La calibración existe porque el STS3215 **no tiene un "reset" de posición**: la posición
reportada (0-4095) es una lectura de encoder y el cero físico depende de cómo se montó el
horn del servo. Es la misma motivación del script propio
`STServo_Python/calibrate_servo_offset.py` (ver [Relevancia](#5-relevancia-para-el-proyecto-brazorobotico)).

### 4.2 Doble persistencia

La calibración vive en **dos lugares** que deben coincidir:

1. **EEPROM del motor** (memoria no volátil del servo), vía `write_calibration`
   (feetech.py:268). Con protocolo 0 escribe:
   - `Homing_Offset` (addr 31, 2 bytes)
   - `Min_Position_Limit` (addr 9, 2 bytes)
   - `Max_Position_Limit` (addr 11, 2 bytes)
2. **Archivo JSON** en el host, vía `_save_calibration` (`Robot` en robot.py:162).

`is_calibrated` (feetech.py:227) compara ambos: `read_calibration()` lee de los motores
`Min_Position_Limit`, `Max_Position_Limit` y (protocolo 0) `Homing_Offset`, y verifica que
el conjunto de motores y los rangos (y offsets, en protocolo 0) coincidan con
`self.calibration` (cargado del JSON). Con protocolo 1 los offsets no se comparan.

### 4.3 Ruta del JSON y estructura

Ruta (robot.py:49-56):

```python
self.calibration_dir  = config.calibration_dir or HF_LEROBOT_CALIBRATION / ROBOTS / self.name
self.calibration_fpath = self.calibration_dir / f"{self.id}.json"
```

- `HF_LEROBOT_CALIBRATION` = variable de entorno `HF_LEROBOT_CALIBRATION`, o por defecto
  `~/.cache/huggingface/lerobot/calibration` (deriva de `HF_LEROBOT_HOME`, no de
  `LEROBOT_HOME`, que está deprecado).
- `ROBOTS = "robots"` (constantes.py:45).
- **OJO**: la carpeta usa `self.name = "so_follower"`, **no** `so101`. La ruta completa
  efectiva es:

  ```
  ~/.cache/huggingface/lerobot/calibration/robots/so_follower/<id>.json
  ```

  (o `$HF_LEROBOT_CALIBRATION/robots/so_follower/<id>.json` si se define la variable).
- El JSON se carga/guarda con `draccus` (`config_type("json")`). Estructura efectiva de
  `dict[str, MotorCalibration]`:

  ```json
  {
    "shoulder_pan": {
      "id": 1,
      "drive_mode": 0,
      "homing_offset": -1947,
      "range_min": 91,
      "range_max": 4031
    },
    "shoulder_lift": { "id": 2, "drive_mode": 0, "homing_offset": -16, "range_min": 27, "range_max": 3981 },
    "elbow_flex":   { "id": 3, "drive_mode": 0, "homing_offset": 291, "range_min": 128, "range_max": 3798 },
    "wrist_flex":   { "id": 4, "drive_mode": 0, "homing_offset": 1932, "range_min": 50, "range_max": 3985 },
    "wrist_roll":   { "id": 5, "drive_mode": 0, "homing_offset": 250, "range_min": 0, "range_max": 4095 },
    "gripper":      { "id": 6, "drive_mode": 0, "homing_offset": -281, "range_min": 156, "range_max": 4043 }
  }
  ```

  (los valores numéricos son ilustrativos; solo los nombres de clave, IDs y campos son
  canónicos del formato).

### 4.4 Flujo de `SOFollower.calibrate()`

`SOFollower.calibrate()` (so_follower.py:115):

1. **¿Existe archivo de calibración?** Si `self.calibration` ya está cargado (el JSON del
   id existe), pregunta al usuario:

   ```
   Press ENTER to use provided calibration file associated with the id <id>, or type 'c' and press ENTER to run calibration:
   ```

   - `ENTER` → escribe la calibración del archivo a los motores
     (`bus.write_calibration(self.calibration)`) y termina.
   - `'c'` → continúa con calibración nueva.

2. **Preparación**: `bus.disable_torque()` (desbloquea EEPROM vía `Lock=0`) y escribe
   `Operating_Mode = POSITION` en todos los motores.

3. **Homing (cero físico)**: pide al usuario

   ```
   Move <robot> to the middle of its range of motion and press ENTER....
   ```

   y ejecuta `set_half_turn_homings()` (motors_bus.py:775), que:
   - `reset_calibration()`: escribe `Homing_Offset = 0`, `Min_Position_Limit = 0` y
     `Max_Position_Limit = max_res` (= 4095).
   - Lee `Present_Position` crudo de cada motor.
   - Calcula el offset de medio giro: `homing_offset = pos - int(max_res / 2)`
     (= `pos - 2047` en STS3215), de modo que la posición actual pase a reportar
     exactamente 2047 (el punto medio del encoder).
   - Escribe `Homing_Offset` por motor.

4. **Registro de rangos de movimiento** (`record_ranges_of_motion`, motors_bus.py:803),
   con excepción de `wrist_roll`:

   ```
   Move all joints except 'wrist_roll' sequentially through their entire ranges of motion.
   Recording positions. Press ENTER to stop...
   ```

   Con el torque deshabilitado, el método lee `Present_Position` en bucle, actualiza
   min/max de cada motor y muestra una tabla `NAME | MIN | POS | MAX` en vivo, hasta que se
   presiona Enter. Lanza `ValueError` si algún motor quedó con min == max (no se movió).
   Tras la grabación, `wrist_roll` se fuerza a `range_min = 0`, `range_max = 4095`
   (es un eje de giro continuo de vuelta completa).

5. **Persistencia**: construye el dict `MotorCalibration` con `drive_mode=0`, y:
   - `bus.write_calibration(self.calibration)` → escribe `Homing_Offset`,
     `Min_Position_Limit`, `Max_Position_Limit` en el EEPROM de cada motor.
   - `self._save_calibration()` → guarda el JSON en `calibration_fpath`.
   - Imprime `Calibration saved to <ruta>`.

### 4.5 CLI

**`lerobot-calibrate`** (`src/lerobot/scripts/lerobot_calibrate.py`, 110 líneas):

```bash
lerobot-calibrate \
    --robot.type=so101_follower \
    --robot.port=/dev/ttyACM0 \
    --robot.id=my_follower
```

- Requiere exactamente uno de `--teleop.*` o `--robot.*` (el `__post_init__` lanza
  `ValueError` si ambos o ninguno).
- Elige dispositivo con `make_robot_from_config` / `make_teleoperator_from_config`,
  conecta con `connect(calibrate=False)` (sin auto-calibración), ejecuta
  `device.calibrate()` y desconecta en `finally`.

**`lerobot-find-joint-limits`** (`lerobot_find_joint_limits.py`, 227 líneas): con
teleoperación, ejecuta un bucle de control (teleop → `send_action` → `get_observation`) y
aplica **cinemática directa** desde un URDF para medir los límites de las articulaciones y
los límites del efector final:

```bash
lerobot-find-joint-limits \
  --robot.type=so100_follower --robot.port=<port> --robot.id=black \
  --teleop.type=so100_leader --teleop.port=<port> --teleop.id=blue \
  --urdf_path=<ruta>/so101_new_calib.urdf \
  --target_frame_name=gripper \
  --teleop_time_s=30 --warmup_time_s=5 --control_loop_fps=30
```

- Fases: *warmup* (5 s sin registrar) y *recording* (30 s moviendo cada articulación a sus
  topes); imprime `max_ee`/`min_ee` (x, y, z) y `max_pos`/`min_pos` (radianes).
- El URDF recomendado es `Simulation/SO101/so101_new_calib.urdf` del repo
  TheRobotStudio/SO-ARM100.

**`lerobot-setup-motors`** (asociado, documentado en so101.mdx): asigna ID y baudrate a
cada motor en el EEPROM, conectando el controlador a **un solo motor a la vez**, fuera del
daisy-chain (ver [Particularidades](#47-particularidades)).

### 4.6 `is_calibrated` y desajuste en `connect()`

Al conectar, si no hay archivo de calibración o el archivo no coincide con los motores
(`is_calibrated` falso), `connect()` llama automáticamente a `calibrate()`, que despliega
la elección interactiva ENTER / 'c' descrita arriba. Esto permite:

- **Primera vez**: sin JSON → calibración completa (homing + rangos).
- **Cambio de firmware/reset de motores**: el desajuste de rangos/offsets dispara el
  diálogo; se puede restaurar desde el archivo (ENTER) o recalibrar ('c').

### 4.7 Particularidades

- **`wrist_roll` (id 5)**: rango forzado `[0, 4095]` en la calibración (giro completo).
- **Gripper (id 6)**: normalización `RANGE_0_100` y límites de seguridad especiales en
  `configure()` (ver [3.4](#34-configure)); el calibrado de su rango es igual al resto
  (homing + rangos), pero al ser una pinza el rango registrado corresponde a la apertura
  física, y `100` = abierta.
- **Espejo 1:1 entre leader y follower**: la calibración debe coincidir entre ambos brazos
  para que, en la misma posición física, reporten los mismos valores (esto es lo que permite
  que una política entrenada en un brazo funcione en otro, y que la teleoperación sea un
  mapeo directo).
- **`setup_motors()`** (so_follower.py:173): itera los motores en **orden inverso**
  (empieza por el `gripper`, id 6). Por cada uno pide conectar el controlador **solo a ese
  motor** y ejecuta `bus.setup_motor(motor)`, que escanea baudrate/ID (protocolo 0:
  `broadcast_ping`), deshabilita torque, escribe el ID destino y el `Baud_Rate` de 1 Mbaud
  en el EEPROM, y reconfigura el bus. Los motores nuevos vienen con ID 1; esta etapa es
  obligatoria una vez antes de armar el brazo.
- **Cámaras y observaciones**: la calibración de motores es independiente de las cámaras;
  el JSON solo contiene los 6 `MotorCalibration`.

### 4.8 Errores comunes

| Error / síntoma | Causa y tratamiento |
| --- | --- |
| `Some Motors use different firmware versions` | Firmware no uniforme entre los 6 motores (`_assert_same_firmware`). Actualizar con el software de Feetech. |
| `Missing motor IDs` / `Motors with incorrect model numbers` | El `ping` del handshake no encontró un ID o el modelo no es `sts3215` (777). Revisar cableado, daisy-chain, alimentación y `--port`. |
| `Could not connect on port ...` (`ConnectionError`) | Puerto incorrecto o permisos; probar `lerobot-find-port` y, en Linux, `sudo chmod 666 /dev/ttyACM0`. |
| `Incorrect status packet!` | Paquete de estado corrupto en el `sync_read` (típico con varios ejes en movimiento). Mitigado por `num_read_retries` (2 por defecto). |
| Lecturas fuera de `[0, 4095]` o negativas | Bit 4 del registro `Phase` (0x12) activo; se limpia en `configure_motors()` para `sts3215`. |
| `connect()` calibra de forma inesperada | `connect()` asume el brazo en reposo y auto-calibra si `is_calibrated` es falso; usar `connect(calibrate=False)` para controlar el momento. |

---

## 5. Relevancia para el proyecto BrazoRobotico

El proyecto propio opera sobre el mismo hardware (bus Feetech STS3215, `scservo_sdk`) y ya
tiene dos herramientas en `STServo_Python/`:

- **`calibrate_servo_offset.py`** (194 líneas): calibra el cero (`OFS`, registro 31-32) y los
  límites de recorrido de **un servo a la vez**, por CLI. Detalles de implementación:
  desbloquea el EEPROM con `unLockEprom`, escribe offset (sign-magnitude con **bit de signo 11**,
  rango [−2047, 2047] según el datasheet `ST3215 memory register map`, addr 0x1F "Position
  correction") con `--target`/`--reset`, escribe límites con `--min`/`--max`, re-bloquea con
  `LockEprom` y verifica. Convención unificada con LeRobot:
  `Present_Position = Actual_Position - Homing_Offset (mod 4096)`. OJO: el signo y el bit son
  los de Feetech (bit 11); usar el bit 15 (convención de `Goal_Position`) rompe el homing
  (fue el bug detectado en la primera corrida real de `calibrate-arm.py`).
- **`servo_control_ui.py`** (449 líneas): GUI Tkinter con 6 sliders para comandar posición
  de los servos 1..6 sobre el bus (1 Mbaud, `/dev/ttyACM0`), con lectura de
  `Present_Position`/`Present_Speed` por `GroupSyncRead` en un hilo de fondo
  (`ServoBusWorker`), escrituras limitadas en tasa y cola thread-safe.

**Conceptos de LeRobot directamente aplicables al brazo propio:**

1. **Homing offset y límites** — la misma idea de `calibrate_servo_offset.py`; LeRobot
   agrega la calibración *por brazo completo* y persistida en JSON, que es la base para
   reproducibilidad entre sesiones.
2. **Normalización** — los modos `DEGREES`/`RANGE_0_100`/`RANGE_M100_100` son el puente
   entre cuentas de encoder crudas y unidades físicas (grados / porcentaje de apertura).
   Aplicar esta capa evita que la lógica de control dependa del montaje mecánico.
3. **PID y límites de seguridad** — ganancias P=16 / I=0 / D=32 y, sobre todo, los topes de
   torque/corriente/sobrecarga de la pinza son un patrón de seguridad que el proyecto propio
   puede replicar en el control de trayectorias (ROS 2).
4. **Bucle pasivo** — el follower de LeRobot es un dispositivo sin bucle propio; el control
   (frecuencia, procesado, clipping) vive fuera. Es una separación limpia que encaja con el
   diseño de un nodo de control en ROS 2.
5. **`max_relative_target`** — recorte de la acción relativa por seguridad; equivalente a
   una limitación de velocidad en el espacio de articulaciones.

---

## 6. Tabla de referencia rápida

**IDs y normalización de motores** (`SOFollower.__init__`):

| Motor | ID | Modelo | Norm mode |
| ----- | -- | --- | --- |
| `shoulder_pan` | 1 | `sts3215` | `DEGREES` (o `RANGE_M100_100`) |
| `shoulder_lift` | 2 | `sts3215` | ídem |
| `elbow_flex` | 3 | `sts3215` | ídem |
| `wrist_flex` | 4 | `sts3215` | ídem |
| `wrist_roll` | 5 | `sts3215` | ídem |
| `gripper` | 6 | `sts3215` | `RANGE_0_100` |

**Registros clave de la tabla de control STS3215** (`STS_SMS_SERIES_CONTROL_TABLE`):

| Registro | Dirección | Tamaño | Nota |
| --- | --- | --- | ---- |
| `Firmware_Major_Version` | 0 | 1 | solo lectura |
| `Firmware_Minor_Version` | 1 | 1 | solo lectura |
| `Model_Number` | 3 | 2 | solo lectura; STS3215 = 777 |
| `ID` | 5 | 1 | EEPROM |
| `Baud_Rate` | 6 | 1 | 1 Mbaud = 0 |
| `Min_Position_Limit` | 9 | 2 | EEPROM |
| `Max_Position_Limit` | 11 | 2 | EEPROM |
| `Max_Torque_Limit` | 16 | 2 | EEPROM (gripper = 500) |
| `Phase` | 18 | 1 | bit 4 (0x10) se limpia |
| `P_Coefficient` | 21 | 1 | EEPROM (16) |
| `D_Coefficient` | 22 | 1 | EEPROM (32) |
| `I_Coefficient` | 23 | 1 | EEPROM (0) |
| `Protection_Current` | 28 | 2 | gripper = 250 |
| `Homing_Offset` | 31 | 2 | EEPROM; sign-magnitude bit 11 |
| `Operating_Mode` | 33 | 1 | POSITION = 0 |
| `Overload_Torque` | 36 | 1 | gripper = 25 |
| `Torque_Enable` | 40 | 1 | SRAM |
| `Acceleration` | 41 | 1 | SRAM |
| `Goal_Position` | 42 | 2 | SRAM; sign-magnitude bit 15 |
| `Lock` | 55 | 1 | 0 = desbloquea EEPROM |
| `Present_Position` | 56 | 2 | solo lectura; sign-magnitude bit 15 |
| `Maximum_Acceleration` | 85 | 1 | fábrica (254) |

**Comandos CLI**:

| Comando | Uso |
| --- | --- |
| `lerobot-calibrate --robot.type=so101_follower --robot.port=<port> --robot.id=<id>` | Calibración del follower |
| `lerobot-find-joint-limits ... --urdf_path=<urdf> --target_frame_name=gripper` | Límites de articulación y efector |
| `lerobot-setup-motors --robot.type=so101_follower --robot.port=<port>` | IDs y baudrate (un motor a la vez) |
| `lerobot-teleoperate --robot.type=so101_follower ... --teleop.type=so101_leader ...` | Bucle de teleoperación |

**Rutas**:

| Elemento | Ruta |
| --- | ---- |
| JSON de calibración | `~/.cache/huggingface/lerobot/calibration/robots/so_follower/<id>.json` (o `$HF_LEROBOT_CALIBRATION/...`) |
| Clase del follower | `lerobot/src/lerobot/robots/so_follower/so_follower.py` |
| Config del follower | `lerobot/src/lerobot/robots/so_follower/config_so_follower.py` |
| Clase base `Robot` | `lerobot/src/lerobot/robots/robot.py` |
| Bus de motores (normalización, calibración a nivel bus) | `lerobot/src/lerobot/motors/motors_bus.py` |
| Driver Feetech | `lerobot/src/lerobot/motors/feetech/feetech.py` |
| Tablas de control STS/SCS | `lerobot/src/lerobot/motors/feetech/tables.py` |
| CLI de calibración | `lerobot/src/lerobot/scripts/lerobot_calibrate.py` |
| CLI de límites | `lerobot/src/lerobot/scripts/lerobot_find_joint_limits.py` |
| Guía oficial SO-101 | `lerobot/docs/source/so101.mdx` |

---

## 7. Referencias

Repositorio LeRobot local (`/home/ezequiel/proyecto-final/lerobot`):

- `src/lerobot/robots/so_follower/so_follower.py` — `SOFollower`, aliases, ciclo de vida,
  `calibrate()`, `configure()`, `get_observation()`, `send_action()`.
- `src/lerobot/robots/so_follower/config_so_follower.py` — `SOFollowerConfig`,
  `SOFollowerRobotConfig`, registro `so101_follower`/`so100_follower`.
- `src/lerobot/robots/robot.py` — clase base `Robot`, persistencia de calibración.
- `src/lerobot/robots/utils.py` — `make_robot_from_config`, `ensure_safe_goal_position`.
- `src/lerobot/robots/bi_so_follower/bi_so_follower.py` — `BiSOFollower`.
- `src/lerobot/motors/motors_bus.py` — `MotorCalibration`, `MotorNormMode`, `_normalize`/
  `_unnormalize`, `set_half_turn_homings`, `record_ranges_of_motion`, `sync_read`/`sync_write`,
  torque.
- `src/lerobot/motors/feetech/feetech.py` — `FeetechMotorsBus`, handshake, monkeypatch,
  calibración a nivel bus, torque.
- `src/lerobot/motors/feetech/tables.py` — tablas de control, baudrates, resolución,
  encoding.
- `src/lerobot/motors/encoding_utils.py` — `encode/decode_sign_magnitude`.
- `src/lerobot/utils/constants.py` — `HF_LEROBOT_CALIBRATION`, `ROBOTS`.
- `src/lerobot/scripts/lerobot_calibrate.py`, `lerobot_find_joint_limits.py`,
  `lerobot_teleoperate.py`.
- `docs/source/so101.mdx` — guía oficial de armado, setup de motores y calibración.

Proyecto BrazoRobotico (`/home/ezequiel/proyecto-final/BrazoRobotico`):

- `STServo_Python/calibrate_servo_offset.py` — calibración de offset/límites por servo.
- `STServo_Python/servo_control_ui.py` — GUI de control de posición de 6 servos.

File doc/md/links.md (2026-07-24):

# Links útiles
## Herramientas de seguimiento
- Usare un tablero kanban en JIRA para hacer el seguimiento de mis tareas. 
    - Link al tablero: https://ealegremendoza.atlassian.net/jira/software/projects/KAN/boards/1

- Voy llevando una bitácora en el archivo del siguiente link.
    - Link: https://docs.google.com/document/d/15SSJkKiB1PeQPN0kVh5Vpq75p_l4SLlW58fwhfUnh_U/edit?usp=drive_link

- Repositorio para compartir archivos con los docentes.
    - Link: https://frbautneduar-my.sharepoint.com/:f:/g/personal/stapino_frba_utn_edu_ar/IgBXhhozbZdMSYAqC1IhuUROAWqo8cG5XLlbY5q3OoX4uok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
    
## Referencias de otros proyectos similares
Los siguientes links deben tomarse como referencias para el proyecto.
Ver referencias.md

## ESP32
- [ESP32 WROOM 32](https://www.espboards.dev/esp32/esp32-wroom/)
- [Getting Started with the ESP32 Development Board](https://randomnerdtutorials.com/getting-started-with-esp32/)
- [ESP32 Dev board Pinout, Specifications, datasheet and Schematic](https://www.etechnophiles.com/esp32-dev-board-pinout-specifications-datasheet-and-schematic/#power-pins)

## Robotica
- [Robot Learning: A Tutorial](https://huggingface.co/spaces/lerobot/robot-learning-tutorial)
- [lerobot github repository](https://github.com/huggingface/lerobot)
- [lerobot assembly tutorial](https://huggingface.co/docs/lerobot/so101)
- [LeRobot SO-ARM101 Robotic Arm - Assembly and Setup Guide\](https://www.youtube.com/watch?v=70GuJf2jbYk)
- [SO101 Arms: Calibration and Motor Configuration](https://www.youtube.com/watch?v=Nhfda8h7e2I)

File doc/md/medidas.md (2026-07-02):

# Medidas
## Servo STS3215
|id|real(mm)|simulación(mm)|simulación(101%)(mm)|
|---|---|---|---|
|a|31.8|31.8|32.118|
|b|24.7|24.7|24.947|
|c|18.44|18.4|18.584|
|d|14|14|14.14|
|e|45.48|||
|f|29|||
|g|33|||
|h||||
|i||||
|j||||
|k||||
|l|35|||
|m||||
|dGear|5.7|||
|dPlastic|6|||

|i||||
|j||||
|k||||
|l|35|||
|m||||
|dGear|5.7|||
|dPlastic|6|||

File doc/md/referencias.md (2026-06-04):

# Referencias

## Proyectos similares
Los siguientes links deben tomarse como referencias para el proyecto.

- Brazo Robótico (KUKA inspired): Diseño y Ensamblaje Completo. https://www.youtube.com/watch?v=ixrZgr7dIdw
    - 4 DOF + grip
    - Solo que usa Matlab como UI, yo no estoy pensando usar una aplicación de escritorio. 
    - Tampoco usa ROS, solamente envia ordenes de movimiento a los servomotores. 
    - Pero ejemplifica lo que quiero hacer. 
    
- Construí un Brazo Robótico (Inspirado en KUKA) desde cero!. https://www.youtube.com/watch?v=D84KoitsC-o
    - 4 DOF + grip
    - Me gusta más el diseño.
    - Solo que usa Matlab como UI, yo no estoy pensando usar una aplicación de escritorio. 
    - Tampoco usa ROS, solamente envia ordenes de movimiento a los servomotores. 
    - Pero ejemplifica lo que quiero hacer. 
    
- Brazo robótico con Arduino - Robotic Arm - Guardar/Reproducir/Exportar/Importar Movimientos. https://www.youtube.com/watch?v=1b1YxPmp97I
    - 5 DOF +grip
    - Solo que usa Matlab como UI, yo no estoy pensando usar una aplicación de escritorio. 
    - Tampoco usa ROS, solamente envia ordenes de movimiento a los servomotores. 
    - Pero ejemplifica lo que quiero hacer. 
    - El proveedor provee archivos formato STEP para hacer modificaciones.
    
- Testing of Feetech STS3215 Servomotor: Backlash, Repeatability, and Torque
    - Link https://robonine.com/testing-of-feetech-sts3215-servomotor-backlash-repeatability-and-torque/
    
## Brazo robótico elegido
- Realizaré el brazo robótico que se muestra en el proyecto SO-ARM100.
    - Video ejemplo: https://www.youtube.com/watch?v=nyuowI5lGRw
    - Imagen de referencia del brazo robótico (voy a construir el blanco):  https://www.hiwonder.com/products/lerobot-so-101?variant=42198960177239#gallery-10
    - Repositorio del proyecto (incluye los archivos para impresión 3D): https://github.com/TheRobotStudio/SO-ARM100/tree/main/Simulation
    - Información sobre el servo STS3215: https://robonine.com/testing-of-feetech-sts3215-servomotor-backlash-repeatability-and-torque/

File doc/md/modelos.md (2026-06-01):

# Modelos 3D de brazos robóticos para imprimir
- Este modelo es una sola pieza. Es para decoración. https://www.printables.com/model/1405519-kuka-based-robotic-arm-replica

- Este modelo es solamente una visualización del brazo KUKA en 3D. https://sketchfab.com/3d-models/robotic-arm-kuka-0211a7f80bdc48f784af6796913af96b

- 4DOF Robotic Arm (KUKA Inspired). Precio $4mil. https://cults3d.com/en/3d-model/gadget/4dof-kuka-inspired-robotic-arm

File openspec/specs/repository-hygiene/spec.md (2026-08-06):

# Repository Hygiene

## Purpose

Keep the git repository free of machine-local and regenerable artifacts, so
clones stay small and portable.

## Requirements

### REQ-HYG-001: Never commit the virtualenv
The Python virtualenv under `STServo_Python/stservo-env/` is regenerable via
`requirements.txt` and machine-specific (absolute paths, platform wheels).
It is ignored by `.gitignore` and must never be tracked.

#### Scenario: A new clone
- **Given** a fresh clone of the repository
- **When** the developer creates `STServo_Python/stservo-env` with
  `python -m venv` and installs `STServo_Python/requirements.txt`
- **Then** the working tree matches the tracked files with no venv bloat

### REQ-HYG-002: .gitignore only affects untracked files
Ignore rules have no effect on already-tracked files. If a file was
committed before its ignore rule existed, it must be removed from the index
with `git rm --cached` (keeping it on disk), then committed.

#### Scenario: A tracked file matches an ignore rule
- **Given** `.vscode/browse.vc.db*` was committed before being added to
  `.gitignore`
- **When** `git rm --cached` is run on those files and committed
- **Then** the files stay on disk but stop appearing as modified

### REQ-HYG-003: Ignored content in this repository
The `.gitignore` ignores `STServo_Python/stservo-env/`, `**/__pycache__/`,
`.vscode/browse.vc.db*`, and `.atl/` (local tooling cache).

## Design

- Tracked Python entry points live outside the venv (e.g.
  `STServo_Python/servo_control_ui.py`), importing the SDK from
  `stservo-env/` via a `sys.path` insert.
- Use `git check-ignore -v <path>` to verify why a path is ignored and
  `git check-ignore --no-index` to test rules against tracked paths.

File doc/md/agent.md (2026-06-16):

# Titulo del proyecto
Brazo robótico programable mediante ROS para automatización de tareas repetitivas basado en grabación y reproducción de trayectorias.

## Fundamentos
Ver idea base, y fundamentos en el archivo fundamentos.md

## Documentación de respaldo
Ver documentación de respaldo del proyecto en respald.md

## Propuesta de proyecto
La propuesta fue basada en lo descrito en fundamentos.md
Ver propuesta de proyecto aprobada por la catedra en el archivo propuesta.md

## Herramienta de seguimiento
Ver links.md
    
## Requisitos
Ver requisitos del proyecto en el archivo requisitos.md

## Referencias del proyecto
Ver referencias.md

## Tareas
Ver tareas del proyecto en tareas.md

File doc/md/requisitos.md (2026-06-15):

# Requisitos del proyecto

## Título del proyecto

Brazo robótico programable mediante ROS para automatización de tareas repetitivas basado en grabación y reproducción de trayectorias.

## Descripción general

El proyecto consiste en el desarrollo de un brazo robótico de bajo costo, fabricable mediante impresión 3D, orientado a tareas repetitivas de manipulación liviana.

El sistema deberá permitir que un usuario enseñe una tarea moviendo manualmente el brazo, registre la trayectoria realizada y luego reproduzca dicha trayectoria de forma automática. El objetivo es automatizar tareas simples de pick-and-place sin requerir que el usuario programe manualmente los movimientos del robot.

El proyecto se desarrollará como un prototipo funcional para entorno interior, educativo, de laboratorio o de automatización liviana.

## Alcance del proyecto

El alcance inicial del proyecto incluye:

* Construcción de un brazo robótico de bajo costo basado en piezas impresas en 3D.
* Manipulación de objetos pequeños y livianos.
* Movimiento manual del brazo para enseñanza de tareas.
* Grabación de trayectorias.
* Almacenamiento de trayectorias.
* Selección de trayectorias previamente grabadas.
* Reproducción automática de trayectorias.
* Borrado de trayectorias almacenadas.
* Interfaz de usuario local para operación básica.
* Visualización del estado del sistema.
* Control de movimiento mediante ROS 2.
* Validación previa mediante simulación.
* Alimentación desde la red eléctrica.
* Diseño preparado para futuras expansiones, como visión artificial, inteligencia artificial, telemetría e interfaz remota.

Quedan fuera del alcance inicial:

* Detección automática de objetos mediante cámara.
* Visión artificial.
* Inteligencia artificial aplicada a la toma de decisiones.
* Teleoperación remota avanzada.
* Aplicación de escritorio para control remoto.
* Control por voz.
* Operación en ambientes industriales agresivos.
* Manipulación de cargas pesadas.

## Modos de operación

### Modo enseñanza

En este modo, el usuario mueve manualmente el brazo robótico para enseñarle una tarea. El sistema deberá registrar la secuencia de posiciones realizada por el usuario.

Este modo se corresponde con la función de programación por demostración.

### Modo reproducción

En este modo, el brazo robótico ejecuta automáticamente una trayectoria previamente almacenada.

El sistema deberá reproducir la secuencia de movimientos de forma consistente, permitiendo automatizar tareas repetitivas.

### Modo detenido o seguro

En este modo, el sistema no ejecuta movimientos automáticos. Deberá utilizarse ante una condición anormal, error, parada solicitada por el usuario o finalización de operación.

## Definiciones técnicas adoptadas

### Objeto liviano

Para este proyecto se considera objeto liviano a todo objeto cuya masa no supere los 200 g, considerando que el brazo será impreso en 3D y que se utilizará para tareas de automatización liviana.

### Objeto pequeño

Para este proyecto se considera objeto pequeño a todo objeto que pueda ser tomado por la pinza del brazo sin requerir herramientas especiales ni modificaciones mecánicas adicionales. La dimensión exacta queda pendiente de definir.

Como criterio de validación, el objeto deberá poder ser agarrado, sostenido, trasladado y liberado entre dos posiciones predefinidas.

### Tarea repetitiva

Se considera tarea repetitiva a una secuencia de movimientos que pueda ser enseñada una vez por el usuario y luego ejecutada varias veces por el brazo robótico.

### Trayectoria

Se considera trayectoria a la secuencia ordenada de posiciones articulares y tiempos asociados que permiten reproducir un movimiento enseñado por el usuario.

### Posición de referencia

Se considera posición de referencia, a una configuración conocida del brazo desde la cual se puede iniciar o finalizar una operación de forma ordenada.

## Requisitos de usuario y operación

### R1.0 - Enseñanza manual de tareas

El usuario deberá poder enseñar una tarea moviendo manualmente el brazo, sin necesidad de escribir código.

El sistema deberá permitir que el usuario coloque el brazo en modo enseñanza, mueva el brazo hacia las posiciones deseadas y registre la trayectoria realizada.

### R1.1 - Facilidad de uso

El usuario deberá poder operar el sistema sin conocimientos avanzados de programación, robótica o electrónica.

La operación principal deberá estar basada en acciones simples como iniciar, grabar, guardar, seleccionar, reproducir, borrar, detener, agarrar y liberar.

### R1.2 - Preparación rápida de tareas

El usuario deberá poder enseñar una nueva tarea en pocos minutos.

El sistema deberá reducir el tiempo necesario para adaptar el brazo a una nueva operación repetitiva.

## Requisitos de manipulación y movimiento

### R2.0 - Manipulación de objetos

El brazo robótico deberá permitir agarrar, sostener, trasladar y liberar objetos livianos entre posiciones predefinidas.

El peso máximo objetivo para el prototipo inicial será de 200 g.

El sistema deberá estar orientado a tareas de pick-and-place de baja carga, tales como traslado de piezas pequeñas, objetos de laboratorio, componentes livianos o elementos de demostración.

### R2.1 - Precisión funcional

El brazo deberá mover objetos entre posiciones predefinidas con precisión suficiente para tareas de pick-and-place.

Como prueba de validación funcional, el sistema deberá poder trasladar un objeto liviano desde una posición inicial hacia una posición final definida.

Como prueba de precisión demostrativa, se propone que el sistema pueda colocar un anillo sobre un dedo de una mano impresa en 3D.

### R2.2 - Repetibilidad

El sistema deberá ejecutar una misma trayectoria varias veces obteniendo resultados consistentes.

La repetibilidad será considerada aceptable cuando el brazo pueda repetir una trayectoria grabada sin perder la secuencia de movimientos ni fallar en la toma o liberación del objeto dentro del escenario de prueba definido.

## Requisitos de gestión de trayectorias

### R3.0 - Grabación de trayectorias

El sistema deberá registrar la secuencia de movimientos realizada por el usuario durante una sesión de enseñanza.

La grabación deberá incluir las posiciones articulares necesarias para reproducir posteriormente el movimiento.

### R3.1 - Almacenamiento de tareas

El sistema deberá permitir guardar las trayectorias registradas por el usuario.

Cada trayectoria almacenada deberá poder identificarse posteriormente para su selección y reproducción.

### R3.2 - Reproducción automática

El brazo robótico deberá ejecutar automáticamente una trayectoria previamente guardada.

Durante la reproducción, el sistema deberá mover el brazo siguiendo la secuencia registrada durante la etapa de enseñanza.

### R3.3 - Selección de tareas

El usuario deberá poder seleccionar qué trayectoria almacenada desea ejecutar.

La selección deberá realizarse desde la interfaz local del sistema.

### R3.4 - Eliminación de tareas

El usuario deberá poder borrar trayectorias almacenadas que ya no sean necesarias.

El sistema deberá evitar que una trayectoria eliminada quede disponible para reproducción.

### R3.5 - Conservación de tareas

Las trayectorias grabadas deberán conservarse luego de apagar y volver a encender el equipo.

El sistema deberá contar con almacenamiento persistente para evitar que el usuario tenga que enseñar nuevamente una tarea ya registrada.

## Requisitos de interfaz de usuario

### R4.0 - Interfaz de usuario local

El sistema deberá contar con una interfaz local que permita operar las funciones principales del brazo.

La interfaz deberá permitir, como mínimo:

* Encender o iniciar el sistema de operación.
* Seleccionar modo de enseñanza.
* Iniciar grabación de trayectoria.
* Guardar trayectoria.
* Seleccionar trayectoria almacenada.
* Reproducir trayectoria.
* Borrar trayectoria.
* Detener la operación.

### R4.1 - Visualización de estado

El sistema deberá informar al usuario el estado actual del brazo robótico.

Como mínimo, se deberán contemplar los siguientes estados:

* Sistema listo.
* Modo enseñanza.
* Grabando trayectoria.
* Trayectoria guardada.
* Reproduciendo trayectoria.
* Tarea finalizada.
* Error.
* Sistema detenido.

## Requisitos de seguridad e inicialización

### R5.0 - Encendido y apagado seguro

El usuario deberá poder encender y apagar el brazo robótico de forma sencilla y segura.

El sistema no deberá iniciar movimientos automáticos inesperados al energizarse.

### R5.1 - Detención de operación

El sistema deberá permitir detener la ejecución de una tarea ante una situación inesperada o condición anormal.

La función de detención deberá tener prioridad sobre la ejecución de trayectorias.

### R5.2 - Inicialización del sistema

El brazo deberá realizar una preparación inicial antes de comenzar la operación normal.

Durante la inicialización, el sistema deberá preparar los servicios de control, verificar el estado general y dejar el brazo en condiciones conocidas de operación.

### R5.3 - Posición de referencia

El brazo deberá contar con una posición de referencia para iniciar o finalizar operaciones.

La posición de referencia deberá utilizarse para ordenar el ciclo de trabajo, facilitar la repetición de tareas y reducir errores al iniciar una reproducción.

## Requisitos de software y control

### R6.0 - Operación autónoma local

El brazo deberá poder ejecutar sus funciones principales sin requerir una computadora externa durante el uso normal.

La computadora integrada deberá ejecutar la lógica de control, la gestión de trayectorias y la comunicación con la interfaz de usuario.

### R6.1 - Organización del control del sistema

El software deberá organizarse de forma modular para coordinar el movimiento del brazo, el estado de operación, la gestión de trayectorias y la interfaz de usuario.

El sistema deberá separar, como mínimo, las siguientes responsabilidades:

* Control del brazo.
* Lectura de estado de los servomotores.
* Grabación de trayectorias.
* Reproducción de trayectorias.
* Gestión de trayectorias almacenadas.
* Interfaz de usuario.
* Seguridad y estados de operación.

### R6.2 - Plataforma de control

El sistema deberá utilizar ROS 2 como plataforma principal de software para la implementación de la lógica de control, comunicación entre módulos y futura integración con simulación.

### R6.3 - Lectura de estado del brazo

El sistema deberá conocer el estado de las articulaciones del brazo durante la operación.

La lectura de estado deberá permitir registrar trayectorias, reproducir movimientos y detectar condiciones anormales.

### R6.4 - Control de actuadores

El sistema deberá enviar comandos de movimiento a los actuadores del brazo robótico.

El control deberá permitir ejecutar movimientos manuales asistidos, grabación y reproducción automática de trayectorias.

### R6.5 - Arranque automático del sistema de control

El sistema deberá iniciar automáticamente los servicios necesarios al encenderse.

El usuario no deberá ejecutar manualmente comandos internos del sistema para comenzar la operación normal del producto.

## Requisitos de hardware e integración física

### R7.0 - Uso en entorno interior

El producto deberá estar pensado para operar en espacios interiores de trabajo, laboratorio o aula.

El prototipo inicial no estará diseñado para operar a la intemperie, bajo lluvia, polvo excesivo, humedad elevada o ambientes industriales agresivos.

### R7.1 - Alimentación por red eléctrica

El sistema deberá poder alimentarse desde la red eléctrica disponible en el lugar de uso.

Para el contexto de uso previsto, se considera alimentación desde red domiciliaria de 220 VCA y 50 Hz, mediante una fuente de alimentación adecuada para el sistema.

La alimentación interna del equipo deberá proveer las tensiones necesarias para los actuadores, la computadora integrada, la interfaz de usuario y los módulos auxiliares.

### R7.2 - Fabricación de bajo costo

El brazo robótico deberá contemplar una construcción que permita reducir costos de fabricación y facilitar la reposición de piezas.

La estructura mecánica principal deberá fabricarse mediante impresión 3D, priorizando piezas de bajo costo y fáciles de reemplazar.

### R7.3 - Dimensionamiento preliminar de fuente

El sistema deberá contar con una fuente principal dimensionada para alimentar simultáneamente el brazo robótico, la computadora integrada y la interfaz de usuario.

Como criterio preliminar de diseño, se adopta una fuente principal switching de 12 VCC y 20 A como mínimo.

Este dimensionamiento contempla:

* Alimentación de servomotores del brazo (en modo bloqueado).
* Alimentación de la computadora integrada (considerando expansiones de procesamiento de imágen e IA).
* Alimentación de la interfaz de usuario.
* Margen de seguridad para picos de consumo.
* Posibilidad de incorporar convertidores DC-DC para las tensiones internas requeridas.

El dimensionamiento final deberá validarse mediante mediciones de consumo durante las pruebas del prototipo.

### R7.4 - Actuadores del brazo

El brazo utilizará servomotores inteligentes con realimentación de posición para permitir grabación y reproducción de trayectorias.

El prototipo inicial estará basado en servomotores STS3215 o equivalentes funcionales.

Los actuadores deberán permitir:

* Control de posición.
* Lectura de posición.
* Lectura de estado.
* Comunicación con el controlador del brazo.
* Ejecución de movimientos repetitivos.

### R7.5 - Capacidad de carga

El brazo deberá estar diseñado para manipular objetos de hasta 200 g en el prototipo inicial.

Este valor representa el objetivo de carga útil del proyecto y deberá validarse experimentalmente.

El brazo no estará destinado a manipular cargas pesadas ni objetos que comprometan la estabilidad mecánica del conjunto.

### R7.6 - Material de impresión

Para la etapa de prototipo se utilizará PLA o PLA+.

Para una versión final o de mayor robustez se contempla el uso de PETG en piezas estructurales, siempre que la impresora disponible y los ensayos mecánicos lo permitan.

### R7.7 - Modelo mecánico de referencia

El diseño mecánico tomará como referencia el proyecto SO-ARM100/SO-ARM101.

El proyecto no construirá dos brazos separados de tipo líder y seguidor. En su lugar, se construirá un único brazo capaz de funcionar como brazo de enseñanza durante la grabación y como brazo ejecutor durante la reproducción.

### R7.8 - Gabinete e integración electrónica

El sistema deberá contar con una integración física para alojar la electrónica, la alimentación y la interfaz de usuario.

El gabinete o soporte de electrónica deberá proteger los componentes internos frente a contactos accidentales durante el uso normal.

## Requisitos de validación y pruebas

### R8.0 - Validación previa de funcionamiento

El sistema deberá permitir verificar el comportamiento del brazo antes de operar físicamente.

La validación previa podrá realizarse mediante simulación, pruebas parciales o ensayos controlados de movimiento.

### R8.1 - Simulación

El sistema deberá contar con un modelo de simulación que permita validar movimientos y funcionalidades antes de su implementación física.

La simulación deberá utilizarse para reducir errores durante la puesta en marcha y facilitar el desarrollo del control.

### R8.2 - Prueba de manipulación

El sistema deberá superar una prueba de manipulación en la cual el brazo tome un objeto liviano, lo traslade y lo libere en una posición predefinida.

### R8.3 - Prueba de repetibilidad

El sistema deberá ejecutar una misma trayectoria repetidas veces manteniendo un resultado consistente.

La prueba deberá realizarse con una trayectoria previamente grabada por el usuario.

### R8.4 - Prueba de precisión funcional

El sistema deberá superar una prueba de precisión funcional acorde al objetivo del proyecto.

Se propone que el brazo pueda colocar un anillo sobre un dedo de una mano impresa en 3D.

### R8.5 - Validación de consumo eléctrico

Sería deseable implementar un monitoreo del consumo eléctrico del sistema para poder limitarlo y realizar secuencias de detención preventivas.

El consumo eléctrico del sistema deberá medirse durante las pruebas del prototipo.

La medición deberá contemplar, como mínimo:

* Sistema encendido en reposo.
* Movimiento manual.
* Grabación de trayectoria.
* Reproducción automática.
* Movimiento con objeto liviano.
* Condiciones de mayor esfuerzo mecánico.

El resultado de estas mediciones deberá utilizarse para confirmar o ajustar el dimensionamiento de la fuente.

## Requisitos de expansiones futuras

### R9.0 - Expansión futura con visión artificial e inteligencia artificial

El sistema inicial no incluirá visión artificial ni inteligencia artificial.

Sin embargo, el diseño deberá contemplar la posibilidad de incorporar en futuras versiones:

* Cámara.
* Reconocimiento de objetos.
* Procesamiento de imágenes.
* Clasificación de objetos.
* Selección automática de objetos a manipular.
* Algoritmos de asistencia inteligente.

Estas funciones se consideran fuera del alcance inicial del proyecto.

### R9.1 - Expansión futura con telemetría

El sistema deberá contemplar la posibilidad de incorporar en futuras versiones funciones de telemetría.

La telemetría podrá incluir:

* Registro de estados del sistema.
* Registro de errores.
* Registro de trayectorias ejecutadas.
* Monitoreo de consumo.
* Monitoreo de posición.
* Monitoreo de temperatura o carga de actuadores, si el hardware lo permite.

Estas funciones se consideran deseables para diagnóstico, mantenimiento y mejora del prototipo.

### R9.2 - Expansión futura de interfaz remota

El sistema inicial no dependerá de una aplicación externa para su operación normal.

Sin embargo, deberá poder evolucionar hacia una interfaz remota de supervisión, configuración o monitoreo.

Esta expansión podrá implementarse mediante una aplicación de escritorio, panel web o herramienta equivalente.

### R9.3 - Expansión futura de herramientas

El brazo deberá contemplar la posibilidad de incorporar herramientas o accesorios de manipulación específicos en futuras versiones.

Estas herramientas podrán incluir variantes de pinza, soportes, adaptadores o efectores finales especializados.

### R9.4 - Expansión futura de interfaz local
Sería deseable que el sistema de interfaz local también cuente con potenciómetros dedicados al movimiento de cada servomotor en el caso de que el operario quisiera manipular el brazo de esa forma en lugar de tocarlo. Esto puede resultar útil al momento de hacer pruebas.

## Restricciones del proyecto

El proyecto estará sujeto a las siguientes restricciones:

* El desarrollo será realizado por un único integrante.
* El alcance deberá mantenerse acotado para poder finalizar el prototipo dentro del plazo académico.
* El sistema inicial no incluirá visión artificial ni inteligencia artificial.
* El sistema inicial no incluirá teleoperación remota avanzada.
* El brazo estará orientado a objetos livianos.
* El prototipo estará destinado a uso interior.
* La estructura será fabricada mediante impresión 3D.
* Las especificaciones finales deberán validarse experimentalmente durante la etapa de pruebas.

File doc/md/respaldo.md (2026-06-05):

# Documento de respaldo
## Titulo del proyecto
Brazo robótico programable mediante ROS para automatización de tareas repetitivas basado en grabación y reproducción de trayectorias.

## Introducción
El proyecto consiste en el desarrollo de un brazo robótico orientado a la automatización de tareas repetitivas de manipulación de objetos, implementando un sistema básico de programación por demostración (Programming by Demonstration, PbD).

## Objetivo
El objetivo principal es construir un manipulador robótico capaz de aprender trayectorias mediante el movimiento manual realizado por el usuario y posteriormente reproducirlas de forma automática con precisión y repetibilidad.

## Misión
Mi misión es desarrollar una plataforma robótica de bajo costo y alta accesibilidad que elimine la barrera técnica de la programación compleja en entornos industriales y educativos. A través de la implementación de Programación por Demostración (PbD), busco que operarios y estudiantes puedan automatizar tareas de manipulación de forma intuitiva, simplemente "enseñando" al robot mediante el movimiento manual.

## Descripción del equipo
El equipo consiste en un manipulador robótico de 5 grados de libertad (DOF) más un grip (pinza). El hardware se basa en el diseño SO-ARM100, con piezas impresas en 3D (PLA/PETG) y servomotores de precisión Feetech STS3215.

### Diagrama en bloques
Diagrama en bloques
- Interfaz de Usuario (Display LCD 20X4 y Botonera): Permite las funciones de grabar, seleccionar, reproducir y borrar trayectorias.
- Computadora Integrada: Ejecuta framework ROS2, gestionando la lógica de cinemática y el almacenamiento de datos.
- Controlador de Servos: Traduce las órdenes de ROS a señales para los 6 motores.
- Actuadores (Servomotores): Ejecutan el movimiento físico del brazo y la pinza.

## Necesidad que cubre
Automatización de tareas de pick-and-place de precisión en líneas de montaje o estaciones de testing electrónico donde el volumen de producción no justifica la inversión en robots industriales de alta gama.

## ¿Cómo actualmente resuelve la necesidad el usuario del producto a realizar?
Actualmente, las opciones en el mercado se dividen en:
- Trabajo manual: Sujeto a fatiga, errores humanos y menor velocidad constante.
- Robots industriales (ej. KUKA): Altamente costosos, requieren personal especializado en programación y una infraestructura compleja.
- Kits educativos simples: No poseen la precisión necesaria para tareas industriales ni cuentan con la robustez de un ecosistema como ROS.

Este proyecto se posiciona en el punto medio: precisión industrial con simplicidad de uso doméstico.

## Análisis FODA
### Fortalezas
- Uso de ROS (estándar de la industria).
- Costo reducido por fabricación 3D.
- Programación kinestésica intuitiva.

### Oportunidades
- Creciente demanda de automatización en PyMEs.
- Posibilidad de expansión futura (visión/IA).
- Entornos educativos interesados en robótica.

### Debilidades
- Limitación de carga (objetos livianos).
- Dependencia de calidad de impresión 3D.
- Interfaz inicial solo por botones (sin aplicación de escritorio).

### Amenazas
- Competencia de kits chinos de bajo costo.
- Inestabilidad en costos de componentes importados (servomotores y controlador).

## Descripción del desafío tecnológico a resolver
El mayor desafío consiste en la implementación de la lógica de grabación y reproducción sincronizada en ROS. Esto implica capturar los estados de los servomotores en tiempo real mientras el operario los mueve (modo líder), filtrar el ruido de los sensores y reproducirlos con suavidad y precisión (modo seguidor) sin comprometer la estabilidad del sistema.

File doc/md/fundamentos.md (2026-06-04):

# Fundamentos
## Titulo del proyecto
Brazo robótico programable mediante ROS para automatización de tareas repetitivas basado en grabación y reproducción de trayectorias.

## Idea
La idea:
1. El usuario mueve manualmente el brazo
2. El sistema registra posiciones
3. El brazo reproduce automáticamente la secuencia

## Qué quiero hacer?
- Quiero hacer un brazo robótico que sea capaz de agarrar y mover objetos de un lugar a otro.
- Quiero que tenga un modo de funcionamiento en el cual se puedan grabar trayectorias para que se puedan automatizar operaciones. Esto entiendo que sería Programacion por demostracion (PbD).
- Quiero que los movimientos del brazo sean precisos.
- Quiero hacer el proyecto con ROS.

## Qué cosas no contendrá el entregable para la materia?
El brazo robótico no contará con:
- Cámara
- Procesamiento de imágenes
- Detección de objetos mediante imágenes y algoritmos de IA.
- Software en PC para controlar el brazo robotico. En esta instancia, no se vinculará el brazo robótico a la PC. Se usará una botonera asociada al brazo para grabar, reproducir y borrar tareas.

El brazo robótico no será:
- un robot autónomo inteligente
- un sistema de IA
- un robot humanoide

## Para quiénes lo quiero hacer?
- Industrias que requieran automatizar rápidamente lineas de montaje.
    - Operarios que no requieran conocimientos de programacion para manipular el brazo. Simplemente presionar grabar, mover el robot y luego reproducir.

## Para qué lo quiero hacer?
- Automatizar tareas repetitivas en lineas de montaje.

## Aplicaciones
- Pick and place de precisión.

## Qué me gustaría que hiciera el brazo de acá a diciembre?
	- Mover con precisión objetos de un lugar a otro.
	- Grabar trayectorias para reproducirlas automáticamente.
	
## Cómo lo quiero hacer?
- Conseguir modelo de brazo 3D para imprimir y para exportar a GAZEBO.
- Conseguir controlador de servos: https://www.hiwonder.com/products/serial-bus-servo-controller
- Conseguir servos: https://www.hiwonder.com/products/hts-35h?_pos=1&_sid=f8aa987be&_ss=r
- Imprimir brazo en 3D. Aun no decido si 5DOF o 6DOF. Usar servos comunes.
- Adaptar modelo 3D a servos de presición HTS-35H.
- Imprimir nuevo modelo de brazo 3D.
- Conseguir placa controladora. Aún no decido si usa beaglebone black o jetson nano. La jetson nano deberia comprarla: https://developer.nvidia.com/embedded/learn/get-started-jetson-nano-devkit
- Programar en ROS la logica de cinematica del brazo.
- Agregar un boton que permita encender el equipo.
- Agregar controles para grabar, reproducir y borrar tarea. 
- Grabar hasta 3 tareas.

## Qué quisiera agregar a futuro? (Post proyecto)
    - Agregar cámara de profundidad y LLM para reconocimiento de objetos.
    - Agregar micrófono para recibir comandos de voz.
    - Agregar parlantes para recibir feedback de parte del robot.
    - Diseño de pinza modular para:
        - pick&place smd
        - grabado láser
        
## Links con videos ejemplos de lo que quiero hacer
- Mini Brazo Robótico con Arduino - Guardar/Reproducir Posiciones.: https://www.youtube.com/watch?v=cWuJPlkmxCE
- Kinesthetic programming by demonstration - Wood planing: https://www.youtube.com/watch?v=psaiT0D9Ag0
    - De este video solo la idea de cómo enseñar al robot. No quiero hacer una herramienta para talla madera.
- Kinesthetic Teaching in Virtual Reality: https://www.youtube.com/watch?v=waBYCskHE-4 
    - De este video solo la idea de cómo enseñar al robot. No quiero hacer nada relacionado a realidad virtual.
- Kinesthetic Teaching with Haptic Feedback | Physical AI | Bota Systems: https://www.youtube.com/watch?v=MCL7rcnIfWE
    - De este video solo la idea de cómo enseñar al robot. No quiero hacer nada de Haptic Feedback ni physical AI.
- This $150 Robot Arm Is The Best Way to Start With Advanced Robotics: https://www.youtube.com/watch?v=59JTCvpG_Ec
    - De este video la idea de cómo enseñar al robot. El proyecto se ve parecido a lo que quiero hacer solo que este usa 2 brazos y yo quisiera usar solo 1 y además este proyecto usa cámara y yo en esta instancia no quiero usarla.
    - Proyecto base de ese video: https://github.com/huggingface/lerobotk
- Curricula for teaching end-users to kinesthetically program collaborative robots : https://pmc.ncbi.nlm.nih.gov/articles/PMC10691692/
- Trajectories and keyframes for kinesthetic teaching: A human-robot interaction perspective: https://sci-hub.box/https://dl.acm.org/doi/10.1145/2157689.2157815

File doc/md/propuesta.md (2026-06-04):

# Propuesta aprobada por la cátedra
El proyecto consiste en el desarrollo de un brazo robótico orientado a la automatización de tareas repetitivas de manipulación de objetos, implementando un sistema básico de programación por demostración (Programming by Demonstration, PbD). El objetivo principal es construir un manipulador robótico capaz de aprender trayectorias mediante el movimiento manual realizado por el usuario y posteriormente reproducirlas de forma automática con precisión y repetibilidad.

El sistema estará basado en el conjunto de librerías de ROS (Robot Operating System), el cual permitirá manejar la lógica de control, cinemática y planificación de movimientos del brazo robótico. El manipulador contará inicialmente con cinco grados de libertad, utilizando servomotores de precisión y una pinza capaz de sujetar objetos livianos para operaciones de tipo pick-and-place.

La metodología PbD busca simplificar la interacción entre el usuario y el brazo robótico al quitar la barrera técnica del lenguaje de programación. Para esto, el brazo dispondrá de una botonera física integrada al sistema que permitirá grabar, reproducir y eliminar trayectorias sin necesidad de utilizar una computadora externa durante la operación normal. De esta manera, el usuario podrá mover manualmente el brazo hacia distintas posiciones, registrando la secuencia de movimientos para luego automatizar tareas repetitivas.

El proyecto está orientado principalmente a aplicaciones de automatización
ligera en entornos industriales y educativos, especialmente en líneas de montaje o
estaciones de testing electrónico donde se requiera trasladar objetos ligeros entre
posiciones predefinidas con precisión.En esta etapa del desarrollo, el sistema no incluirá visión artificial,
procesamiento de imágenes, aprendizaje automático ni navegación autónoma. El
objetivo es concentrarse en la implementación de la lógica de manipulación robótica,
capaz de ejecutar movimientos programados de manera confiable y reproducible.

Con el fin de enfocarse en el desarrollo del software de control, reducir
tiempos y abaratar costos, el proyecto contempla la utilización de modelos 3D
imprimibles desarrollados por terceros y adaptados a las nuevas dimensiones que
puedan surgir de los servomotores a utilizar.

Adicionalmente, el proyecto empleará una simulación del brazo robótico en
entornos virtuales como Gazebo, permitiendo validar el comportamiento del robot
antes de su implementación física.

A futuro, la plataforma podrá expandirse mediante la incorporación de
cámaras, reconocimiento de objetos y herramientas modulares especializadas,
aunque dichas funcionalidades quedan fuera del alcance inicial del proyecto.

Finalmente, se espera que al finalizar esta etapa del proyecto se cuente con
un brazo robótico capaz de reproducir movimientos generados por el usuario
convirtiéndose en una herramienta valiosa al momento de realizar trabajos
repetitivos.

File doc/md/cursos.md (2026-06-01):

# Modelado 3D
## Fusion360
- Es de pago. Mejor usar FreeCAD.

## FreeCAD
- Aprende FreeCAD para impresión 3D: Guía completa, rápida y sencilla (principiante)
    - Link: https://www.youtube.com/watch?v=QZfZ1CAA1Tw

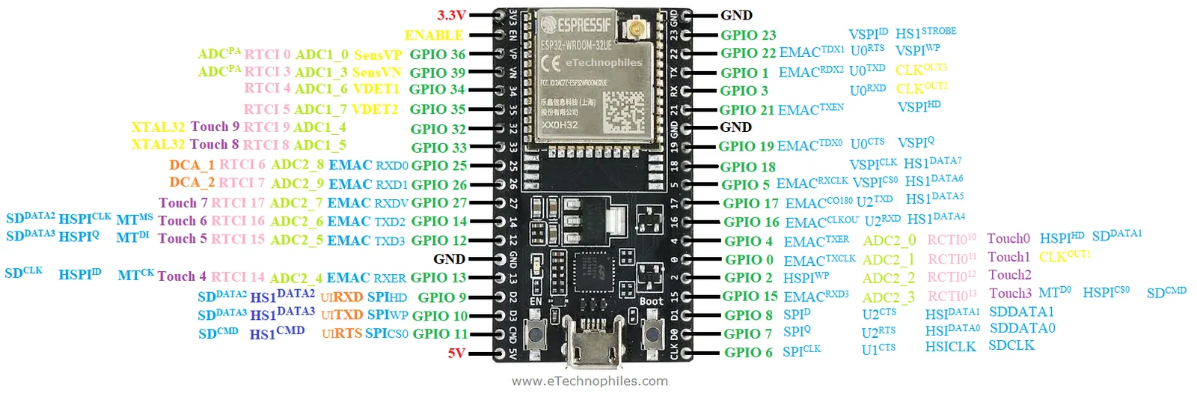
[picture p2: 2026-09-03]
doc/datasheets/esp32_38pin_pinout.webp

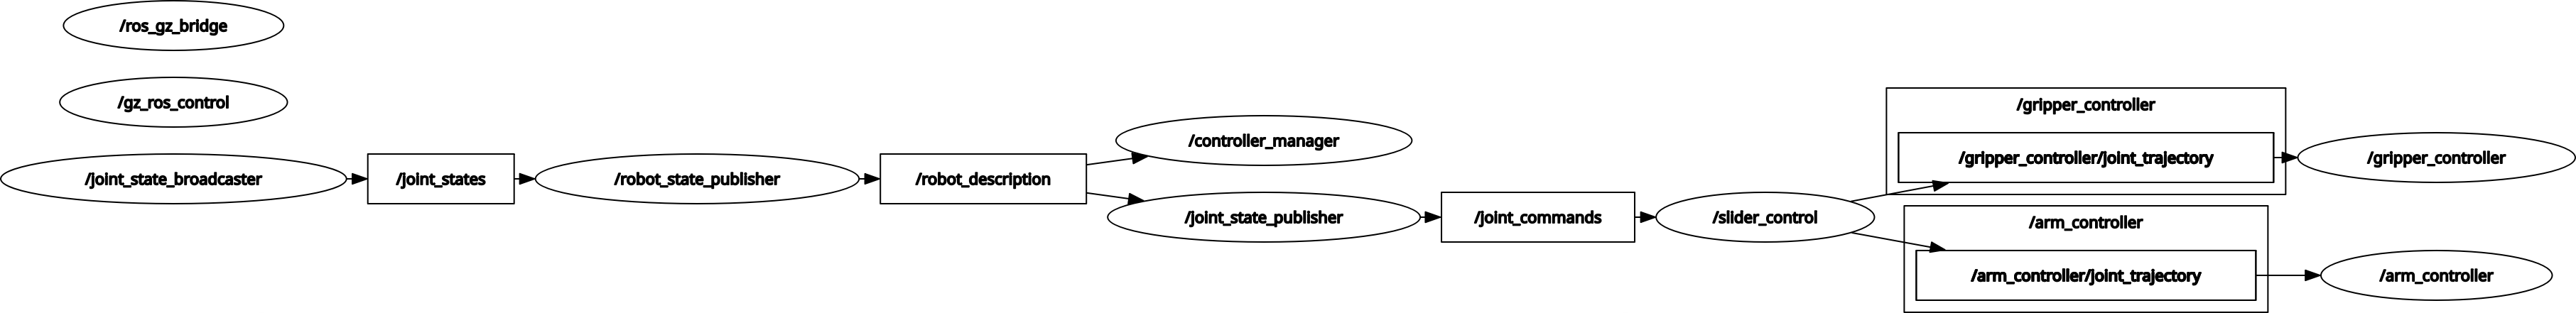
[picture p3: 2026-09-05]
doc/img/rosgraph.png

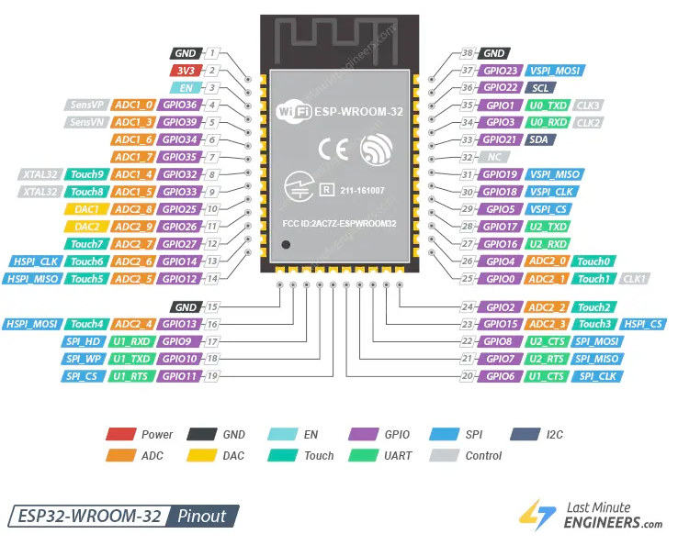
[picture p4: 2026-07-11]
doc/datasheets/esp32-dev-board.png

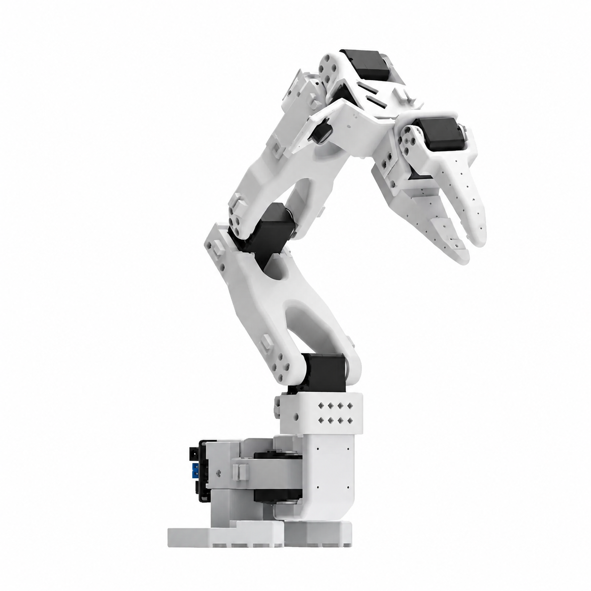
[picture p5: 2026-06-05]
doc/img/SO-ARM101.png

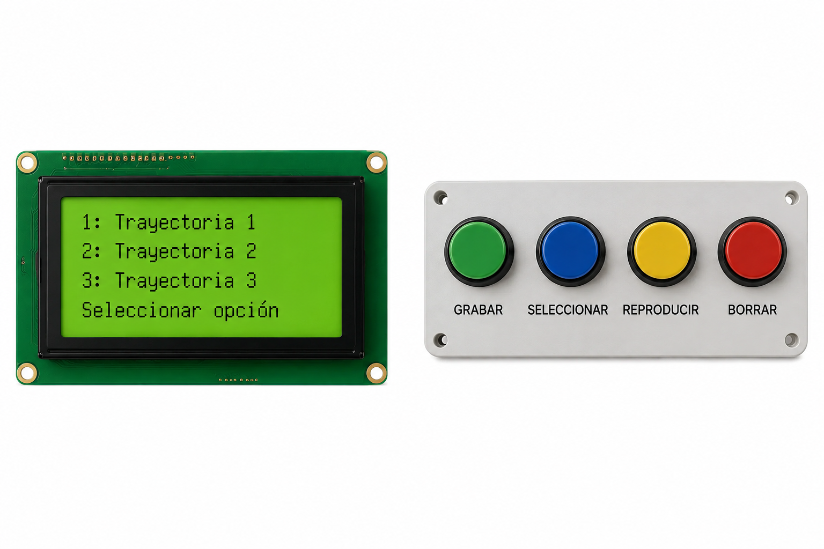
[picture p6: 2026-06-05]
doc/img/display_y_boyonera.png

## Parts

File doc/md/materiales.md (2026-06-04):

# Materiales
- 6 Servos Sts3215 De 7,4 V Para Brazo Robótico So-arm100 De 1
    - Link: https://www.mercadolibre.com.ar/6-servos-sts3215-de-74-v-para-brazo-robotico-so-arm100-de-1/p/MLA2037577958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

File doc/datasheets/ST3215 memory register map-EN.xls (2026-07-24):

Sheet: Sheet2
ST3215 Memory Table Parsing -V3.7
 |  | No-load speed（RPM） |  | 49.776 |  | Test voltage (V) |  |  | 7.4V
 |  | No-load speed (step/second) |  | 3400 |  | No-load Current (mA) |  |  | 150
 |  | Maximum effective angle (degree) |  | 360 | Supports multi-turn large-angle control, does not retain revolution count after power loss.
 |  | Resolution (step) |  | 4096
 |  | Minimum resolution angle (degree/step) |  | 0.087890625 |  | Electronic dead zone (degree) |  |  | 0.17578125
 |  | Acceleration (degree/s^2) |  | 8.7890625
 | Memory First Address |  | Function | Number of Bytes | Initial Value | Storage Area | Permission | Minimum Value | Maximum Value | Unit | Value Parsing
0x | DEC | HEX |  | Little-endian |  |  |  |  |  |  | If the functional address uses a two-byte data format, with the low-order byte at the preceding address and the high-order byte at the succeeding address.
0 | 0 | 0 | Firmware major version number | 1 | 3 | EPROM | read only | -1 | -1
1 | 1 | 1 | Firmware minor version number | 1 | 7 | EPROM | read only | -1 | -1
3 | 3 | 3 | Servo major version number | 1 | 9 | EPROM | read only | -1 | -1
4 | 4 | 4 | Servo minor version number | 1 | 3 | EPROM | read only | -1 | -1
5 | 5 | 0x5 | ID | 1 | 1 | EPROM | read/write | 0 | 253 | Baud | A unique identification code on the bus, with no duplicate ID numbers allowed on the same bus. ID number 254 (0xFE) is the broadcast ID, and broadcasts do not receive response packets.
6 | 6 | 0x6 | Baudrate | 1 | 0 | EPROM | read/write | 0 | 7 | None | 0-7 respectively represent baud rates as follows: 1000000, 500000, 250000, 128000, 115200, 76800, 57600, 38400
7 | 7 | 0x7 | Return delay | 1 | 0 | EPROM | read/write | 0 | 254 | 2us | The minimum unit is 2us, and the maximum allowable setting for response delay is 254*2=508us
8 | 8 | 0x8 | Response status level | 1 | 1 | EPROM | read/write | 0 | 1 | None | 0: Except for read and PING instructions, other instructions do not return response packets. 1: Return response packets for all instructions
9 | 9 | 0x9 | Minimum angle | 2 | 0 | EPROM | read/write | -32766 | -- | Step | Set the minimum value limit for the motion range, which should be smaller than the maximum angle limit. When performing multi-turn absolute position control, this value is set to 0.
B | 11 | 0xB | Maximum angle | 2 | 4095 | EPROM | read/write | -- | 32767 | Step | Set the maximum value limit for the motion range, which should be greater than the minimum angle limit. When performing multi-turn absolute position control, this value is set to 0.
D | 13 | 0xD | Maximum temperature | 1 | 70 | EPROM | read/write | 0 | 100 | °C | The maximum operating temperature limit, when set to 70, means the maximum temperature is 70 degrees Celsius, with a precision setting of 1 degree Celsius.
E | 14 | 0xE | Maximum input voltage | 1 | 80 | EPROM | read/write | 0 | 254 | 0.1V | If the maximum input voltage is set to 80, then the maximum operating voltage limit is 8.0V, with a precision setting of 0.1V.
F | 15 | 0xF | Minimum input voltage | 1 | 40 | EPROM | read/write | 0 | 254 | 0.1V | If the minimum input voltage is set to 40, then the minimum operating voltage limit is 4.0V, with a precision setting of 0.1V.
10 | 16 | 0x10 | Maximum torque | 2 | 1000 | EPROM | read/write | 0 | 1000 | 0.10% | Set the maximum output torque limit for the servo motor, where 1000 corresponds to 100% of the locked-rotor torque. Assign this value to address 48 upon power-up as the torque limit.
12 | 18 | 0x12 | Phase | 1 | 12 | EPROM | read/write | 0 | 254 | None | Special function byte, do not modify unless there are specific requirements. Please refer to the special byte bit analysis for further details.
13 | 19 | 0x13 | Unloading conditions | 1 | 44 | EPROM | read/write | 0 | 254 | None | Bit0 Bit1 Bit2 Bit3 Bit4 Bit5 set corresponding bit to 1 to enable the corresponding protection. Voltage Sensor Temperature Current Angle Overload set corresponding bit to 0 to disable the corresponding protection
14 | 20 | 0x14 | LED alarm conditions | 1 | 47 | EPROM | read/write | 0 | 254 | None | Bit0 Bit1 Bit2 Bit3 Bit4 Bit5 set the corresponding bit to 1 to enable flashing LED. Voltage Sensor Temperature Current Angle Overload set corresponding bit to 0 to disable the corresponding protection
15 | 21 | 0x15 | Position loop P (Proportional) coefficient | 1 | 32 | EPROM | read/write | 0 | 254 | None | Proportional coefficient of control motor
16 | 22 | 0x16 | Position loop D (Differential) coefficient | 1 | 32 | EPROM | read/write | 0 | 254 | None | Differential coefficient of control motor
17 | 23 | 0x17 | Position loop I (Integral) coefficient | 1 | 0 | EPROM | read/write | 0 | 254 | None | Integral coefficient of the control motor
18 | 24 | 0x18 | Minimum starting force | 2 | 16 | EPROM | read/write | 0 | 1000 | 0.1% | Set the minimum output startup torque for the servo, where 1000 corresponds to 100% of the locked-rotor torque.
1A | 26 | 0x1A | Clockwise insensitive zone | 1 | 1 | EPROM | read/write | 0 | 32 | Step | The minimum unit is one minimum resolution angle.
1B | 27 | 0x1B | Anti-clockwise insensitive zone | 1 | 1 | EPROM | read/write | 0 | 32 | Step | The minimum unit is a minimum resolution angle.
1C | 28 | 0x1C | Protection current | 2 | 500 | EPROM | read/write | 0 | 511 | 6.5mA | The maximum settable current is 500 * 6.5mA= 3250mA.
1E | 30 | 0x1E | Angle resolution | 1 | 1 | EPROM | read/write | 1 | 3 | None | For the amplification factor of the minimum resolution angle (degree/step) of the sensor, modifying this value can expand the number of control range. When performing the multi-turn control, you need to modify the parameter at address 0x12 by setting BIT4 to 1. This modification will result in the current position feedback value being adjusted to reflect the larger angle feedback.
1F | 31 | 0x1F | Position correction | 2 | 0 | EPROM | read/write | -2047 | 2047 | Step | BIT11 is the direction bit, indicating the positive and negative direction, and other bits can indicate the range of 0-2047 steps.
21 | 33 | 0x21 | Operation mode | 1 | 0 | EPROM | read/write | 0 | 3 | None | 0: position servo mode 1: motor constant speed mode, controlled by parameter 0x2E running speed parameter, the highest bit BIT15 is direction bit. 2: PWM open-loop speed regulation mode, controlled by parameter 0x2Cthe running time parameter, BIT10 is direction bit 3: step servo mode, and the target position of parameter 0x2A is used to indicate the number of steps, and the highest bit BIT15 is the direction bit. When working In mode 3, the minimum and maximum angle limits of 0x9 and 0xB must be set to 0. Otherwise, it is impossible to step indefinitely.
22 | 34 | 0x22 | Protection torque | 1 | 20 | EPROM | read/write | 0 | 100 | 1.0% | Output torque after entering overload protection. If 20 is set, it means 20% of the maximum torque.
23 | 35 | 0x23 | Protection time | 1 | 200 | EPROM | read/write | 0 | 254 | 10ms | The duration for which the current load output exceeds the overload torque and remains is represented by a value, such as 200, which indicates 2 seconds. The maximum value that can be set is 2.5 seconds.
24 | 36 | 0x24 | Overload torque | 1 | 80 | EPROM | read/write | 0 | 100 | 1.0% | The maximum torque threshold for starting the overload protection time countdown can be represented by a value, such as 80, indicating 80% of the maximum torque.
25 | 37 | 0x25 | Speed closed-loop proportional (P) coefficient | 1 | 10 | EPROM | read/write | 0 | 100 | None | Proportional coefficient of speed loop in motor constant speed mode (mode 1)
26 | 38 | 0x26 | Overcurrent protection time | 1 | 200 | EPROM | read/write | 0 | 254 | 10ms | The maximum setting is 254 * 10ms = 2540ms.
27 | 39 | 0x27 | Velocity closed-loop integral (I) coefficient | 1 | 10 | EPROM | read/write | 0 | 254 | 1/10 | In the motor constant speed mode (mode 1), the speed loop integral coefficient (change note: the speed closed loop I integral coefficient is reduced by 10 times compared with version 3.6).
28 | 40 | 0x28 | Torque switch | 1 | 0 | SRAM | read/write | 0 | 128 | None | Write 0: disable the torque output; Write 1: enable the torque output; Write 128: Arbitrary current position correction to 2048.
29 | 41 | 0x29 | Acceleration | 1 | 0 | SRAM | read/write | 0 | 254 | 100 step/s^2 | If set to 10, it corresponds to an acceleration and deceleration rate of 1000 steps per second squared.
2A | 42 | 0x2A | Target location | 2 | 0 | SRAM | read/write | -30719 | 30719 | Step | Each step corresponds to the minimum resolution angle, and it is used in absolute position control mode. The maximum number of steps corresponds to the maximum effective angle.
2C | 44 | 0x2C | Operation time | 2 | 0 | SRAM | read/write | 0 | 1000 | 0.10% | In the PWM open-loop speed control mode, the value range is from 50 to 1000, and BIT10 serves as the direction bit.
2E | 46 | 0x2E | Operation speed | 2 | 0 | SRAM | read/write | 0 | 3400 | step/s | Number of steps per unit time (per second), 50 steps per second = 0.732 RPM (revolutions per minute)
30 | 48 | 0x30 | Torque limit | 2 | 1000 | SRAM | read/write | 0 | 1000 | 1.0% | The initial value of power-on will be assigned by the maximum torque (0x10), which can be modified by the user to control the output of the maximum torque.
37 | 55 | 0x37 | Lock flag | 1 | 0 | SRAM | read/write | 0 | 1 | None | Writing 0: Disables the write lock, allowing values written to the EPROM address to be saved even after power loss. Writing 1: Enables the write lock, preventing values written to the EPROM address from being saved after power loss.
38 | 56 | 0x38 | Current location | 2 | 0 | SRAM | read only | -1 | -1 | Step | Feedback the number of steps in the current position, each step is a minimum resolution angle; Absolute position control mode, the maximum value corresponds to the maximum effective angle.
3A | 58 | 0x3A | Current speed | 2 | 0 | SRAM | read only | -1 | -1 | step/s | Feedback the current speed of motor rotation and the number of steps in unit time (per second).
3C | 60 | 0x3C | Current load | 2 | 0 | SRAM | read only | -1 | -1 | 0.1% | The voltage duty cycle of the current control output driving motor.
3E | 62 | 0x3E | Current voltage | 1 | 0 | SRAM | read only | -1 | -1 | 0.1V | Current servo operation voltage
3F | 63 | 0x3F | Current temperature | 1 | 0 | SRAM | read only | -1 | -1 | °C | Current servo internal operating temperature
40 | 64 | 0x40 | Asynchronous write flag | 1 | 0 | SRAM | read only | -1 | -1 | None | The flag bit for using asynchronous write instructions
41 | 65 | 0x41 | Servo status | 1 | 0 | SRAM | read only | -1 | -1 | None | Bit0 Bit1 Bit2 Bit3 Bit4 Bit5 the corresponding bit is set to 1 to indicate that the corresponding error occurs, Voltage Sensor Temperature Current Angle Overload the corresponding bit is set to 0 to indicate that there is no corresponding error.
42 | 66 | 0x42 | Move flag | 1 | 0 | SRAM | read only | -1 | -1 | None | The sign of the servo is 1 when it is moving, and 0 when it is stopped.
45 | 69 | 0x45 | Current current | 2 | 0 | SRAM | read only | -1 | -1 | 6.5mA | The maximum measurable current is 500 * 6.5mA= 3250mA.

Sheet: Sheet1
 | STS3215内存表参数解析 -V3.7
 |  | 空载速度（RPM） |  | 49.776 |  | 测试电压(V) |  |  | 7.4V
 |  | 空载速度（步/秒） |  | 3400 |  | 空载电流（mA) |  |  | 150
 |  | 最大有效角度（度） |  | 360 | 支持多圈大角度控制，掉电不保存圈数
 |  | 解析度（步） |  | 4096
 |  | 最小分辨角度（度/步） |  | 0.087890625 |  | 电子死区（度） |  |  | 0.17578125
 |  | 加速度（度/s^2） |  | 8.7890625
 | 内存首地址 |  | 功能 | 字节数 | 初始值 | 存储区 | 权限 | 最小取值 | 最大取值 | 单位 | 取值解析
0x | DEC | HEX |  | 低在前 高在后 |  |  |  |  |  |  | 如果功能地址采用两个字节数的数据，低位字节在前面地址，高位字节在后面地址
0 | 0 | 0 | 固件主版本号 | 1 | 3 | EPROM | 只读 | -1 | -1
1 | 1 | 1 | 固件次版本号 | 1 | 7 | EPROM | 只读 | -1 | -1
3 | 3 | 3 | 舵机主版本号 | 1 | 9 | EPROM | 只读 | -1 | -1
4 | 4 | 4 | 舵机次版本号 | 1 | 3 | EPROM | 只读 | -1 | -1
5 | 5 | 0x5 | ID | 1 | 1 | EPROM | 读写 | 0 | 253 | 号 | 总线上唯一的身份识别码，同一总线不可出现重复ID号 254号(OxFE)为广播ID，广播不返回应答包
6 | 6 | 0x6 | 波特率 | 1 | 0 | EPROM | 读写 | 0 | 7 | 无 | 0-7分别代表波特率如下 1000000，500000，250000，128000，115200，76800，57600，38400
7 | 7 | 0x7 | 返回延时 | 1 | 0 | EPROM | 读写 | 0 | 254 | 2us | 最小单位为2us,最大可设置返回延时 254*2=508us
8 | 8 | 0x8 | 应答状态级别 | 1 | 1 | EPROM | 读写 | 0 | 1 | 无 | 0:除读指令与PING指令外其它指令不返回应答包 1:对所有指令返回应答包
9 | 9 | 0x9 | 最小角度限制 | 2 | 0 | EPROM | 读写 | -32766 | -- | 步 | 设置运动行程最小值限制，取值小于最大角度限制，多圈绝对位置控制时此值为0
B | 11 | 0xB | 最大角度限制 | 2 | 4095 | EPROM | 读写 | -- | 32767 | 步 | 设置运动行程最大值限制，取值大于最小角度限制，多圈绝对位置控制时此值为0
D | 13 | 0xD | 最高温度上限 | 1 | 70 | EPROM | 读写 | 0 | 100 | °C | 最高工作温度限制，如设置为70 则最高温度为70摄氏度，设置精度为1摄氏度
E | 14 | 0xE | 最高输入电压 | 1 | 80 | EPROM | 读写 | 0 | 254 | 0.1V | 最高输入电压如设置为80，则最高工作电压限制为8.0V，设置精度为0.1V
F | 15 | 0xF | 最低输入电压 | 1 | 40 | EPROM | 读写 | 0 | 254 | 0.1V | 最低输入电压如设置为40，则最低工作电压限制为4.0V，设置精度为0.1V
10 | 16 | 0x10 | 最大扭矩 | 2 | 1000 | EPROM | 读写 | 0 | 1000 | 0.10% | 设置舵机的最大输出扭矩限制，设1000 = 100% * 堵转扭力， 上电赋值给48号地址转矩限制
12 | 18 | 0x12 | 相位 | 1 | 12 | EPROM | 读写 | 0 | 254 | 无 | 特殊功能字节，无特别需求不可修改,详见特殊字节位解析
13 | 19 | 0x13 | 卸载条件 | 1 | 44 | EPROM | 读写 | 0 | 254 | 无 | Bit0 Bit1 Bit2 Bit3 Bit4 Bit5 对应位设置1为开启相应保护 电压 传感器 温度 电流 角度 过载 对应位设置0为关闭相应保护
14 | 20 | 0x14 | LED报警条件 | 1 | 47 | EPROM | 读写 | 0 | 254 | 无 | Bit0 Bit1 Bit2 Bit3 Bit4 Bit5 对应位设置1为开启闪灯报警 电压 传感器 温度 电流 角度 过载 对应位设置0为关闭闪灯报警
15 | 21 | 0x15 | 位置环P 比例系数 | 1 | 32 | EPROM | 读写 | 0 | 254 | 无 | 控制电机的比例系数
16 | 22 | 0x16 | 位置环D 微分系数 | 1 | 32 | EPROM | 读写 | 0 | 254 | 无 | 控制电机的微分系数
17 | 23 | 0x17 | 位置环I 积分系数 | 1 | 0 | EPROM | 读写 | 0 | 254 | 无 | 控制电机的积分系数
18 | 24 | 0x18 | 最小启动力 | 2 | 16 | EPROM | 读写 | 0 | 1000 | 0.1% | 设置舵机的最小输出启动扭矩，设1000 = 100% * 堵转扭力
1A | 26 | 0x1A | 顺时针不灵敏区 | 1 | 1 | EPROM | 读写 | 0 | 32 | 步 | 最小单位为一个最小分辨角度
1B | 27 | 0x1B | 逆时针不灵敏区 | 1 | 1 | EPROM | 读写 | 0 | 32 | 步 | 最小单位为一个最小分辨角度
1C | 28 | 0x1C | 保护电流 | 2 | 500 | EPROM | 读写 | 0 | 511 | 6.5mA | 最大可设置电流为 500 * 6.5mA= 3250mA
1E | 30 | 0x1E | 角度分辨率 | 1 | 1 | EPROM | 读写 | 1 | 3 | 无 | 对传感器最小分辨角度（度/步）的放大系数，修改此值可以扩展控制圈数 多圈控制时需修改地址0x12参数BIT4置1，当前位置反馈值会被修改为大角度反馈
1F | 31 | 0x1F | 位置校正 | 2 | 0 | EPROM | 读写 | -2047 | 2047 | 步 | BIT11为方向位，表示正负方向，其他位可表示范围为0-2047步
21 | 33 | 0x21 | 运行模式 | 1 | 0 | EPROM | 读写 | 0 | 3 | 无 | 0：位置伺服模式 1：电机恒速模式,用参数0x2E运行速度参数控制，最高位BIT15为方向位 2：PWM开环调速度模式，用参数0x2C 运行时间参数控制，BIT10为方向位 3：步进伺服模式，用参数0x2A 目标位置表示步进步数，最高位BIT15为方向位 工作在模式3时，必须把0x9与0xB 最小最大角度限制设为0，否则不能无限步进
22 | 34 | 0x22 | 保护扭矩 | 1 | 20 | EPROM | 读写 | 0 | 100 | 1.0% | 进入过载保护后输出扭矩，如设20表示20%的最大扭矩
23 | 35 | 0x23 | 保护时间 | 1 | 200 | EPROM | 读写 | 0 | 254 | 10ms | 当前负载输出超过过载扭力并保持的计时时长，如设200表示2秒，最大可设2.5秒
24 | 36 | 0x24 | 过载扭矩 | 1 | 80 | EPROM | 读写 | 0 | 100 | 1.0% | 启动过载保护时间计时的最大扭力阀值，如设80表示80%的最大扭矩
25 | 37 | 0x25 | 速度闭环P比例系数 | 1 | 10 | EPROM | 读写 | 0 | 100 | 无 | 电机恒速模式（模式1）下,速度环比例系数
26 | 38 | 0x26 | 过流保护时间 | 1 | 200 | EPROM | 读写 | 0 | 254 | 10ms | 最大可设置254 * 10ms = 2540ms
27 | 39 | 0x27 | 速度闭环I积分系数 | 1 | 10 | EPROM | 读写 | 0 | 254 | 1/10 | 电机恒速模式（模式1）下,速度环积分系数 （变动备注：速度闭环I积分系数缩小10倍较3.6版本）
28 | 40 | 0x28 | 扭矩开关 | 1 | 0 | SRAM | 读写 | 0 | 128 | 无 | 写0：关闭扭力输出； 写1：打开扭力输出；写128：任意当前位置较正为2048
29 | 41 | 0x29 | 加速度 | 1 | 0 | SRAM | 读写 | 0 | 254 | 100步/s^2 | 如设置为10 则按1000步每秒平方的加减速度变速
2A | 42 | 0x2A | 目标位置 | 2 | 0 | SRAM | 读写 | -30719 | 30719 | 步 | 每步为一个最小分辨角度，绝对位置控制方式，最大对应最大有效角度
2C | 44 | 0x2C | 运行时间 | 2 | 0 | SRAM | 读写 | 0 | 1000 | 0.10% | PWM开环调速度模式下，取值范围50-1000，BIT10为方向位
2E | 46 | 0x2E | 运行速度 | 2 | 0 | SRAM | 读写 | 0 | 3400 | 步/s | 单位时间（每秒）内运动的步数，50步/秒= 0.732 RPM(圈每分钟）
30 | 48 | 0x30 | 转矩限制 | 2 | 1000 | SRAM | 读写 | 0 | 1000 | 1.0% | 上电初始值会由最大扭矩（0x10）赋值，用户可程序修改此值来控制最大扭矩的输出
37 | 55 | 0x37 | 锁标志 | 1 | 0 | SRAM | 读写 | 0 | 1 | 无 | 写0关闭写入锁，写入EPROM地址的值掉电保存 写1打开写入锁，写入EPROM地址的值掉电不保存
38 | 56 | 0x38 | 当前位置 | 2 | 0 | SRAM | 只读 | -1 | -1 | 步 | 反馈当前所处位置的步数，每步为一个最小分辨角度；绝对位置控制方式，最大值对应最大有效角度
3A | 58 | 0x3A | 当前速度 | 2 | 0 | SRAM | 只读 | -1 | -1 | 步/s | 反馈当前电机转动的速度，单位时间（每秒）内运动的步数
3C | 60 | 0x3C | 当前负载 | 2 | 0 | SRAM | 只读 | -1 | -1 | 0.1% | 当前控制输出驱动电机的电压占空比
3E | 62 | 0x3E | 当前电压 | 1 | 0 | SRAM | 只读 | -1 | -1 | 0.1V | 当前舵机工作电压
3F | 63 | 0x3F | 当前温度 | 1 | 0 | SRAM | 只读 | -1 | -1 | °C | 当前舵机内部工作温度
40 | 64 | 0x40 | 异步写标志 | 1 | 0 | SRAM | 只读 | -1 | -1 | 无 | 采用异步写指令时，标志位
41 | 65 | 0x41 | 舵机状态 | 1 | 0 | SRAM | 只读 | -1 | -1 | 无 | Bit0 Bit1 Bit2 Bit3 Bit4 Bit5 对应位被置1表示相应错误出现 电压 传感器 温度 电流 角度 过载 对应位0为无相应该错误
42 | 66 | 0x42 | 移动标志 | 1 | 0 | SRAM | 只读 | -1 | -1 | 无 | 舵机在运动时标志为1，舵机停止时为0
45 | 69 | 0x45 | 当前电流 | 2 | 0 | SRAM | 只读 | -1 | -1 | 6.5mA | 最大可测量电流为 500 * 6.5mA= 3250mA

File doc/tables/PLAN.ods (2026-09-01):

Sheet: REQUERIMIENTOS
Listado de requerimientos |  |  | Última actualización: 19-06-2026
ID | Tipo | Requerimiento | Comentario
R1.0 | Usuario | El usuario debe poder enseñar una tarea moviendo manualmente el brazo. | No debe requerir escritura de código.
R1.1 | Usuario | El sistema debe ser fácil de operar. | Operación mediante acciones simples: iniciar, grabar, guardar, seleccionar, reproducir, borrar, detener, agarrar y liberar.
R1.2 | Usuario | El sistema debe permitir preparar una nueva tarea rápidamente. | La enseñanza de una nueva tarea debería realizarse en pocos minutos.
R2.0 | Manipulación | El brazo debe agarrar, sostener, trasladar y liberar objetos livianos. | Carga objetivo del prototipo: hasta 200 g.
R2.1 | Movimiento | El brazo debe mover objetos entre posiciones predefinidas con precisión funcional. | Prueba funcional: traslado de un objeto liviano entre dos posiciones.
R2.2 | Movimiento | El sistema debe ejecutar una misma trayectoria varias veces con resultados consistentes. | La repetibilidad se valida repitiendo una trayectoria grabada sin fallas.
R3.0 | Trayectorias | El sistema debe registrar trayectorias durante una sesión de enseñanza. | La grabación debe incluir las posiciones articulares necesarias para reproducir el movimiento.
R3.1 | Trayectorias | El sistema debe permitir guardar trayectorias registradas. | Cada trayectoria debe poder identificarse posteriormente.
R3.2 | Trayectorias | El brazo debe reproducir automáticamente una trayectoria guardada. | La reproducción debe seguir la secuencia registrada durante enseñanza.
R3.3 | Trayectorias | El usuario debe poder seleccionar una trayectoria almacenada. | La selección se realiza desde la interfaz local.
R3.4 | Trayectorias | El usuario debe poder borrar trayectorias almacenadas. | Una trayectoria eliminada no debe quedar disponible para reproducción.
R3.5 | Trayectorias | Las trayectorias deben conservarse después de apagar y encender el sistema. | Requiere almacenamiento persistente.
R4.0 | Interfaz | El sistema debe contar con una interfaz local para operar funciones principales. | Debe permitir iniciar, grabar, guardar, seleccionar, reproducir, borrar y detener.
R4.1 | Interfaz | El sistema debe informar el estado actual del brazo. | Estados mínimos: listo, enseñanza, grabando, guardado, reproduciendo, finalizado, error y detenido.
R5.0 | Seguridad | El usuario debe poder encender y apagar el brazo de forma segura. | El sistema no debe iniciar movimientos automáticos inesperados al energizarse.
R5.1 | Seguridad | El sistema debe permitir detener la ejecución ante una condición anormal. | La detención debe tener prioridad sobre la ejecución de trayectorias.
R5.2 | Inicialización | El brazo debe realizar una preparación inicial antes de operar. | Debe preparar servicios de control, verificar estado general y quedar en condiciones conocidas.
R5.3 | Inicialización | El brazo debe contar con una posición de referencia. | Posición conocida para iniciar o finalizar operaciones de forma ordenada.
R6.0 | Software | El brazo debe operar localmente sin requerir computadora externa durante el uso normal. | La computadora integrada ejecuta lógica de control, trayectorias e interfaz.
R6.1 | Software | El software debe organizarse de forma modular. | Módulos mínimos: control, lectura de estado, grabación, reproducción, gestión, interfaz y seguridad.
R6.2 | Software | El sistema debe utilizar ROS 2 como plataforma principal. | ROS 2 se usa para lógica de control, comunicación entre módulos y futura simulación.
R6.3 | Software | El sistema debe conocer el estado de las articulaciones durante la operación. | Requiere lectura de estado para grabar, reproducir y detectar condiciones anormales.
R6.4 | Software | El sistema debe enviar comandos de movimiento a los actuadores. | Debe permitir movimiento manual asistido, grabación y reproducción automática.
R6.5 | Software | El sistema debe iniciar automáticamente los servicios de control. | El usuario no debe ejecutar comandos internos manualmente para operar el producto.
R7.0 | Entorno | El producto debe estar pensado para uso interior. | No está diseñado para intemperie, lluvia, polvo excesivo, humedad elevada o ambientes industriales agresivos.
R7.1 | Alimentación | El sistema debe alimentarse desde la red eléctrica disponible. | Red domiciliaria considerada: 220 VCA, 50 Hz.
R7.2 | Fabricación | El brazo debe contemplar construcción de bajo costo. | Estructura principal fabricada mediante impresión 3D y piezas reemplazables.
R7.3 | Alimentación | La fuente principal debe alimentar brazo, computadora integrada e interfaz. | Criterio preliminar: fuente switching de 12 VCC y 20 A como mínimo.
R7.4 | Actuadores | El brazo debe usar servomotores inteligentes con realimentación de posición. | Prototipo basado en STS3215 o equivalentes funcionales.
R7.5 | Carga | El brazo debe manipular objetos de hasta 200 g. | La carga útil debe validarse experimentalmente.
R7.6 | Materiales | El prototipo debe fabricarse inicialmente en PLA o PLA+. | Para mayor robustez se contempla PETG en piezas estructurales.
R7.7 | Mecánica | El diseño mecánico debe tomar como referencia SO-ARM100/SO-ARM101. | Se construye un único brazo que funciona como enseñanza y ejecución.
R7.8 | Integración | El sistema debe contar con gabinete o soporte para electrónica, alimentación e interfaz. | Debe proteger componentes internos frente a contactos accidentales.
R8.0 | Validación | El sistema debe permitir validar el funcionamiento antes de operar físicamente. | Puede realizarse mediante simulación, pruebas parciales o ensayos controlados.
R8.1 | Simulación | El sistema debe contar con un modelo de simulación. | La simulación debe validar movimientos y funcionalidades antes de la implementación física.
R8.2 | Pruebas | El sistema debe superar una prueba de manipulación. | El brazo debe tomar, trasladar y liberar un objeto liviano.
R8.3 | Pruebas | El sistema debe superar una prueba de repetibilidad. | Debe repetir una trayectoria previamente grabada con resultado consistente.
R8.4 | Pruebas | El sistema debe superar una prueba de precisión funcional. | Prueba propuesta: colocar un anillo sobre un dedo de una mano impresa en 3D.
R8.5 | Consumo | El consumo eléctrico debe medirse durante las pruebas del prototipo. | Medir reposo, movimiento manual, grabación, reproducción, carga liviana y mayor esfuerzo mecánico.
R9.0 | Expansión | El diseño debe contemplar futura visión artificial e inteligencia artificial. | Fuera del alcance inicial; posible incorporación de cámara y reconocimiento de objetos.
R9.1 | Expansión | El sistema debe contemplar futura telemetría. | Posibles registros: estados, errores, trayectorias, consumo, posición, temperatura o carga.
R9.2 | Expansión | El sistema debe poder evolucionar hacia una interfaz remota. | Fuera del alcance inicial; posible aplicación de escritorio.
R9.3 | Expansión | El brazo debe contemplar futuras herramientas o accesorios. | Posibles variantes de pinza, soportes, adaptadores o efectores finales.
R9.4 | Expansión | La interfaz local podría incorporar potenciómetros para manejo manual de servos. | Función deseable para pruebas o manipulación alternativa del brazo.

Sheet: TAREAS
Listado de tareas |  |  |  |  | Última actualización: 07-08-2026
ID | Épica | Tarea | Duración estimada | Dependencias | Entregable / criterio de cierre | Progreso [%] | Totales | Cant.
T01 | Diseño | Definir arquitectura general del sistema. | 2d |  | Diagrama o descripción de arquitectura general aprobada. | 100% | Total de tareas | 60
T02 | Diseño | Definir arquitectura ROS 2 del brazo robótico. | 5d | T01 | Nodos, tópicos, servicios y responsabilidades definidos. | 75% | Tareas completadas | 13
T03 | Diseño | Definir modo líder/grabación y modo seguidor/reproducción. | 1d | T01, T02 | Flujo de operación de ambos modos documentado. | 50% | Tareas en curso | 7
T04 | Diseño | Seleccionar modelo 3D de brazo a utilizar. | 1d | T01 | Modelo de brazo definido y compatible con el alcance del proyecto. | 100% | Tareas por hacer | 40
T05 | Diseño | Seleccionar componentes principales del sistema. | 2d | T01, T04 | Lista de componentes principales definida: servos, driver, fuente, computadora embebida, display y botonera. | 100%
T06 | Diseño | Diseñar esquemático de PCB de interfaz. | 7d | T05 | Esquemático del PCB de interfaz terminado. | 5%
T07 | Diseño | Rutear PCB de interfaz. | 7d | T06 | Layout de PCB de interfaz terminado. | 0%
T08 | Compras | Comprar componentes para PCB de interfaz. | 3d | T06, T07 | Componentes electrónicos disponibles para el ensamblado. | 0%
T09 | Fabricación | Fabricar y validar PCB de interfaz. | 14d | T07, T08 | PCB de interfaz finalizada. | 0%
T10 | Validación | PCB de interfaz validada. | 0d | T09 | PCB de interfaz fabricada, ensamblada y validada eléctricamente. | 0%
T11 | Compras | Comprar servomotores. | 30d | T05 | Servomotores disponibles para el proyecto. | 100%
T12 | Compras | Comprar placa driver para servomotores. | 30d | T05 | Driver disponible y compatible con los servomotores seleccionados. | 100%
T13 | Compras | Comprar fuente de alimentación principal. | 5d | T05 | Fuente disponible y acorde al consumo previsto del sistema. | 100%
T14 | Compras | Comprar display LCD 20x4 y botonera. | 5d | T05 | Interfaz física disponible para integración. | 50%
T15 | Compras | Comprar computadora embebida. | 30d | T05 | Computadora embebida disponible para ejecutar ROS 2 e integrar el sistema. | 0%
T16 | Entorno | Aprender a utilizar impresora 3D. | 15d |  | Impresora 3D instalada, calibrada y probada con impresiones simples. | 100%
T17 | Entorno | Preparar entorno de desarrollo ROS 2. | 15d | T02, T15 | Entorno ROS 2 instalado y probado. | 75%
T18 | Entorno | Preparar repositorio. | 1d | T17 | Estructura de paquetes, carpetas y documentación base creada. | 75%
T19 | Simulación | Modelar brazo para simulación. | 5d | T04, T17 | Modelo del brazo disponible para ROS 2/Gazebo. | 0%
T20 | Simulación | Configurar modelo del brazo en Gazebo. | 5d | T19 | Brazo cargado correctamente en Gazebo. | 0%
T21 | Simulación | Validar movimiento básico en simulación. | 0d | T20 | Movimiento básico verificado en entorno simulado. | 0%
T22 | Actuadores | Implementar control individual de servomotores. | 5d | T10, T11, T12, T13, T17, T18 | Cada servomotor puede recibir comandos individuales desde el sistema. | 0%
T23 | Actuadores | Implementar lectura de posición de cada articulación. | 5d | T22 | Posición de cada articulación disponible para el sistema. | 0%
T24 | Calibración | Implementar calibración inicial del brazo. | 20d | T23 | Procedimiento de calibración ejecutable. | 0%
T25 | Calibración | Implementar posición Home. | 5d | T24 | Posición de referencia definida y alcanzable. | 0%
T26 | Manual | Implementar movimiento manual del brazo. | 5d | T22, T23, T25 | El brazo puede moverse manualmente para enseñanza. | 0%
T27 | Trayectorias | Implementar grabación de trayectorias. | 15d | T22, T23, T26 | Trayectoria registrada con posiciones y tiempos. | 0%
T28 | Trayectorias | Implementar almacenamiento persistente de trayectorias. | 2d | T27 | Trayectorias guardadas y recuperables tras reinicio. | 0%
T29 | Trayectorias | Implementar selección de trayectorias guardadas. | 2d | T28 | Trayectoria seleccionable desde el sistema. | 0%
T30 | Trayectorias | Implementar reproducción de trayectoria seleccionada. | 5d | T28, T29 | Trayectoria almacenada reproducida correctamente. | 0%
T31 | Trayectorias | Implementar eliminación de trayectorias. | 1d | T28, T29 | Trayectorias almacenadas pueden borrarse correctamente. | 0%
T32 | Estados | Implementar estados del sistema: listo, grabando, reproduciendo y error. | 5d | T27, T30, T31 | Estados visibles y coherentes con la operación real. | 0%
T33 | UI | Implementar interfaz con display LCD. | 10d | T10, T14, T32 | Display muestra estados, opciones y mensajes principales del sistema. | 0%
T34 | UI | Implementar interfaz con botonera. | 10d | T10, T14, T32 | Botonera permite operar funciones principales: grabar, reproducir, seleccionar y borrar. | 0%
T35 | Seguridad | Implementar parada de emergencia o detención segura. | 5d | T22, T30, T32, T34 | Ejecución detenible ante una condición anormal o acción del usuario. | 0%
T36 | Inicialización | Configurar arranque automático del sistema. | 3d | T15, T17, T18, T32 | Servicios principales inician al encender el equipo. | 0%
T37 | Fabricación | Imprimir piezas del brazo en PLA para prototipo. | 7d | T04, T11, T16 | Piezas impresas y listas para ensamblaje. | 100%
T38 | Fabricación | Ensamblar estructura mecánica del brazo. | 7d | T11, T37 | Estructura del brazo armada físicamente. | 100%
T39 | Integración | Montar electrónica en gabinete. | 3d | T10, T11, T12, T13, T14, T15, T38 | Electrónica montada y organizada en gabinete. | 20%
T40 | Integración | Cablear alimentación, servos, controlador, computadora embebida, display y botonera. | 1d | T10, T38, T39 | Sistema cableado y listo para pruebas eléctricas. | 0%
T41 | Consumo | Verificar consumo eléctrico del sistema. | 1d | T40 | Consumo medido o estimado y comparado con la capacidad de la fuente. | 0%
T42 | Pruebas | Probar manipulación de objetos livianos. | 1d | T30, T35, T38, T40, T41 | El brazo agarra, mueve y suelta objetos livianos. | 0%
T43 | Pruebas | Probar repetibilidad de trayectorias. | 1d | T42 | Misma trayectoria ejecutada varias veces con resultado consistente. | 0%
T44 | Pruebas | Probar precisión de movimiento. | 1d | T42, T43 | Precisión evaluada contra el criterio definido para el proyecto. | 0%
T45 | Pruebas | Prueba de integración: colocar anillo en dedo impreso en 3D. | 1d | T44 | Prueba final realizada con resultado satisfactorio. | 0%
T46 | Correcciones | Corregir fallas detectadas en pruebas. | 7d | T42, T43, T44, T45 | Fallas críticas corregidas y pruebas repetidas. | 0%
T47 | Validación | Validar manipulación de objetos livianos. | 0d | T42, T46 | Prueba final realizada con resultado satisfactorio. | 0%
T48 | Validación | Validar repetibilidad de trayectorias. | 0d | T43, T46 | Prueba final realizada con resultado satisfactorio. | 0%
T49 | Validación | Validar precisión de movimiento. | 0d | T44, T46 | Prueba final realizada con resultado satisfactorio. | 0%
T50 | Validación | Validar prueba de integración. | 0d | T45, T46 | Prueba final realizada con resultado satisfactorio. | 0%
T51 | Fabricación final | Migrar piezas finales a PETG si corresponde. | 14d | T16, T46 | Piezas finales impresas o decisión documentada de mantener PLA. | 0%
T52 | Documentación | Documentar instalación, uso y operación del sistema. | 10d | T33, T34, T36, T46, T50 | Manual o sección documental de instalación y uso completa. | 0%
T53 | Documentación | Documentar resultados de pruebas y validación final. | 10d | T41, T42, T43, T44, T45, T46, T47, T48, T49, T50 | Informe de pruebas y validación final documentado. | 0%
T54 | Presentación | Preparar presentación final (demo). | 3d | T52, T53 | Presentación, demo y material de exposición preparados. | 0%
T55 | Entrega Final | Entrega final del proyecto. | 0d | T54 | Proyecto entregado con documentación, resultados y validación final completos. | 0%
T56 | Pruebas | Probar rigidez mecánica del brazo. | 2d | T38 | Deflexión del efector final medida bajo una carga de referencia, sin roturas, deformaciones permanentes ni holguras excesivas. | 100%
T57 | Pruebas | Probar capacidad de carga del brazo. | 2d | T56 | El brazo manipula cargas progresivas hasta 200 g sin caída del objeto, pérdida de control, deformación crítica ni consumo anormal. | 100%
T58 | Validación | Validación mecánica del brazo. | 0d | T56, T57 | El brazo cumple con los requisitos mecánicos del proyecto. | 100%
T59 | Pruebas | Testear movimiento de servomotores y driver. | 5d | T11, T12, T13 | Evidencia de pruebas de los dispositivos y documentación de cómo usarlos. | 100%
T60 | Fabricación | Diseñar y fabricar gabinete | 7d | T10, T11, T12, T13, T14, T15, T38 | Gabinete | 0%

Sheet: TRAZABILIDAD
MATRIZ DE TRAZABILIDAD |  |  |  |  |  |  |  | Actualización: | 7 de agosto de 2026
Nombre del proyecto: "Brazo robótico programable mediante ROS para automatización de tareas repetitivas basado en grabación y reproducción de trayectorias"
Categoría | Código | Identificación Requisito | Descripción del Requisito | Objetivo | Implementación | Importancia | Tarea Asociada | Fecha | Comentario | Avance [%]
Usuario y operación | R1.0 | Enseñanza manual de tareas | El usuario deberá poder enseñar una tarea moviendo manualmente el brazo, sin necesidad de programar. | Facilitar la programación por demostración. | Modo de operación manual para enseñanza de trayectorias. | ALTA | T26 | 17/8/2026 |  | 0,00%
Usuario y operación | R1.1 | Facilidad de uso | El usuario deberá poder operar el brazo sin conocimientos de programación ni robótica. | Reducir la barrera de uso para operarios o estudiantes. | Flujo de operación simple para enseñar, guardar, seleccionar, reproducir y borrar tareas. | ALTA | T26, T33, T34 | 25/9/2026 |  | 0,00%
Usuario y operación | R1.2 | Preparación rápida de tareas | El usuario deberá poder enseñar una nueva tarea de manera rápida y sencilla. | Disminuir el tiempo necesario para adaptar el brazo a una nueva operación. | Flujo guiado de enseñanza, grabación y guardado. | MEDIA | T26, T27, T30 | 10/9/2026 |  | 0,00%
Manipulación y movimiento | R2.0 | Manipulación de objetos | El brazo robótico deberá permitir agarrar, sostener, trasladar y liberar objetos livianos entre posiciones predefinidas. | Automatizar tareas simples de traslado de objetos. | Sistema de manipulación y control de movimiento del brazo. | ALTA | T42 | 1/10/2026 |  | 0,00%
Manipulación y movimiento | R2.1 | Precisión funcional | El brazo deberá mover objetos entre posiciones predefinidas con precisión suficiente para tareas de pick-and-place. | Cumplir tareas de manipulación repetitiva de forma confiable. | Control coordinado del movimiento del brazo. | ALTA | T43, T44 | 3/10/2026 |  | 0,00%
Manipulación y movimiento | R2.2 | Repetibilidad | El sistema deberá ejecutar una misma trayectoria varias veces obteniendo resultados consistentes. | Garantizar comportamiento estable en tareas repetitivas. | Control de reproducción de trayectorias y validación de movimientos. | ALTA | T43 | 2/10/2026 |  | 0,00%
Gestión de trayectorias | R3.0 | Grabación de trayectorias | El sistema deberá registrar la secuencia de movimientos realizada por el usuario durante la enseñanza de una tarea. | Permitir que una tarea manual pueda ser almacenada para su posterior automatización. | Módulo de registro de trayectorias. | ALTA | T27 | 1/9/2026 |  | 0,00%
Gestión de trayectorias | R3.1 | Almacenamiento de tareas | El sistema deberá permitir guardar las trayectorias registradas por el usuario. | Conservar tareas enseñadas para reutilizarlas. | Gestor de trayectorias almacenadas. | ALTA | T28 | 3/9/2026 |  | 0,00%
Gestión de trayectorias | R3.2 | Reproducción automática | El brazo robótico deberá ejecutar automáticamente una trayectoria previamente guardada. | Automatizar tareas repetitivas sin intervención continua del usuario. | Modo de reproducción de trayectorias. | ALTA | T30 | 10/9/2026 |  | 0,00%
Gestión de trayectorias | R3.3 | Selección de trayectorias | El usuario deberá poder seleccionar qué trayectoria almacenada desea ejecutar. | Permitir el uso de distintas tareas previamente enseñadas. | Menú o lógica de selección de tareas desde la interfaz local. | ALTA | T29 | 5/9/2026 |  | 0,00%
Gestión de trayectorias | R3.4 | Eliminación de tareas | El usuario deberá poder borrar trayectorias almacenadas que ya no sean necesarias. | Mantener ordenado el conjunto de tareas disponibles. | Función de eliminación dentro del gestor de trayectorias. | MEDIA | T31 | 6/9/2026 |  | 0,00%
Gestión de trayectorias | R3.5 | Conservación de tareas | Las trayectorias grabadas deberán conservarse luego de apagar y volver a encender el equipo. | Evitar que el usuario tenga que enseñar nuevamente una tarea ya registrada. | Almacenamiento persistente de trayectorias. | ALTA | T28 | 3/9/2026 |  | 0,00%
Interfaz de usuario | R4.0 | Interfaz de usuario local | El sistema deberá contar con una interfaz local que permita operar las funciones principales del brazo. | Permitir el uso del producto sin depender de una computadora externa durante la operación normal. | Interfaz local de operación integrada al equipo. | ALTA | T33, T34, T60 | 25/9/2026 |  | 0,00%
Interfaz de usuario | R4.1 | Visualización de estado | El sistema deberá informar al usuario el estado actual del brazo, como listo, grabando, reproduciendo, detenido o error. | Brindar retroalimentación clara durante la operación. | Indicadores de estado en la interfaz local. | ALTA | T33 | 25/9/2026 |  | 0,00%
Seguridad e inicialización | R5.0 | Encendido y apagado seguro | El usuario deberá poder encender y apagar el brazo robótico de forma sencilla y segura. | Evitar arranques o apagados inesperados que afecten la operación. | Secuencia de inicio y apagado controlada. | ALTA | T35 | 30/9/2026 |  | 0,00%
Seguridad e inicialización | R5.1 | Detención de operación | El sistema deberá permitir detener la ejecución de una tarea ante una situación inesperada o condición anormal. | Proteger al usuario, al equipo y al entorno de trabajo. | Función de parada o cancelación de tarea. | ALTA | T35 | 30/9/2026 |  | 0,00%
Seguridad e inicialización | R5.2 | Inicialización del sistema | El brazo deberá realizar una preparación inicial antes de comenzar la operación normal. | Asegurar que el sistema se encuentre en condiciones conocidas antes de operar. | Procedimiento de inicialización del brazo. | ALTA | T36 | 18/9/2026 |  | 0,00%
Seguridad e inicialización | R5.3 | Posición de referencia | El brazo deberá contar con una posición de referencia para iniciar o finalizar operaciones. | Ordenar el ciclo de trabajo y facilitar la repetición de tareas. | Definición de una posición inicial o de reposo. | MEDIA | T25 | 12/8/2026 |  | 0,00%
Software y control | R6.0 | Operación autónoma local | El brazo deberá poder ejecutar sus funciones principales sin requerir una computadora externa durante el uso normal. | Hacer que el producto sea práctico como equipo independiente. | Integración del control, la interfaz y el almacenamiento dentro del equipo. | BAJA | T15 | 21/6/2026 | Aun no lo compré. Estoy diseñando el sistema para usarlo desde la PC por falta de presupuesto. | 0,00%
Software y control | R6.1 | Organización del control del sistema | El producto deberá coordinar de forma ordenada el movimiento del brazo, el estado de operación y la gestión de tareas. | Mantener una lógica de funcionamiento clara, mantenible y ampliable. | Arquitectura interna modular para control, estados y trayectorias. | MEDIA | T01, T02 | 19/7/2026 |  | 87,50%
Hardware e integración física | R7.0 | Uso en entorno interior / Grado de protección | El producto deberá estar pensado para operar en espacios interiores de trabajo o laboratorio. | Adecuar el equipo al contexto de uso previsto. | Diseño del brazo y del gabinete electrónico orientado a operación en interiores. | MEDIA | T60 | 15/7/2026 |  | 0,00%
Hardware e integración física | R7.1 | Alimentación por red electrica | El sistema deberá poder alimentarse desde la red eléctrica disponible en el lugar de uso. | Permitir la operación continua del brazo robótico en un entorno de trabajo. | Sistema de alimentación integrado al conjunto del producto. | ALTA | T41 | 20/7/2026 |  | 0,00%
Hardware e integración física | R7.2 | Fabricación de bajo costo | El brazo robótico deberá contemplar una construcción que permita reducir costos de fabricación y facilitar la reposición de piezas. | Disminuir el costo general del producto y facilitar su mantenimiento o reparación. | Diseño de piezas fabricables mediante impresión 3D. | MEDIA | T04, T16, T37 | 5/8/2026 | Brazo 3D ensamblado | 100,00%
Validación y pruebas | R8.0 | Validación previa de funcionamiento | El sistema deberá permitir verificar el comportamiento del brazo antes de operar físicamente. | Reducir errores durante la puesta en marcha y las pruebas. | Entorno de validación o simulación del comportamiento del brazo. | MEDIA | T21 | 14/8/2026 |  | 0,00%
Validación y pruebas | R8.1 | Simulación | El sistema deberá contar con un modelo de simulación que permita validar funcionalidades antes de su implementación física. | La simulación deberá utilizarse para reducir errores durante la puesta en marcha y facilitar el desarrollo del control. | Elaborar una réplica virtual del brazo robótico. | MEDIA | T21 | 14/8/2026 |  | 0,00%
Validación y pruebas | R8.2 | Prueba de manipulación | El sistema deberá demostrar que puede agarrar, trasladar y liberar un objeto. | Validar que el sistema real sea capaz de realizar las acciones principales del brazo robótico. | Mover un objeto entre dos posiciones específicas. | ALTA | T42 | 28/10/2026 |  | 0,00%
Validación y pruebas | R8.3 | Prueba de repetibilidad | El sistema deberá demostrar que puede ejecutar una misma trayectoria repetidas veces manteniendo el mismo resultado. | Validar repetibilidad del sistema. | Mover el brazo por una trayectoria conocida que involucre a todos las articulaciones del mismo más de 30 veces manteniendo un resultado consistente. | ALTA | T43 | 29/10/2026 |  | 0,00%
Validación y pruebas | R8.4 | Prueba de precisión | El sistema deberá demostrar que puede realizar tareas con determinada presición. | Validar precisión del sistema. | Se propone que el brazo pueda colocar un anillo sobre un dedo de una mano impresa en 3D. | MEDIA | T44 | 30/10/2026 |  | 0,00%
Expansiones futuras | R9.0 | Expansión futura con visión e IA | El sistema inicial no incluirá visión artificial ni inteligencia artificial, pero deberá contemplar la posibilidad de incorporar reconocimiento de objetos en futuras versiones. | Permitir la evolución del producto hacia tareas más avanzadas. | Diseño modular que permita integrar sensores y procesamiento adicional en una etapa posterior. | BAJA | T02, T15 |  |  | 37,50%
Expansiones futuras | R9.1 | Expansión futura con telemetría | El sistema deberá contemplar la posibilidad de incorporar en futuras versiones funciones de monitoreo, registro y consulta del estado operativo. | Facilitar diagnóstico, análisis de uso y mantenimiento futuro. | Diseño preparado para agregar registro de eventos, estados y datos de operación. | BAJA | T02, T15 |  |  | 37,50%
Expansiones futuras | R9.2 | Expansión futura de interfaz remota | El sistema inicial no dependerá de una aplicación externa, pero deberá poder evolucionar hacia una interfaz remota de supervisión o configuración. | Permitir futuras mejoras de operación y mantenimiento. | Arquitectura preparada para integrar comunicación con una aplicación o panel externo. | BAJA | T02, T15 |  |  | 37,50%
Expansiones futuras | R9.3 | Expansión futura de herramientas | El brazo deberá contemplar la posibilidad de incorporar herramientas o accesorios de manipulación específicos en versiones futuras. | Ampliar el rango de aplicaciones del producto. | Diseño funcional preparado para adaptar el extremo de trabajo del brazo. | BAJA | T02, T03, T15 |  |  | 41,67%
Expansiones futuras | R9.4 | Expansión futura de interfaz local | El sistema deberá contemplar la posibilidad de incorporar controles individuales para los movimientos de cada actuador. | Brindar otra forma de manipulación manual del brazo robótico. | Incorporar hardware dedicado para la operación aislada de cada servomotor. | MEDIA | T33, T34 |  |  | 0,00%
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

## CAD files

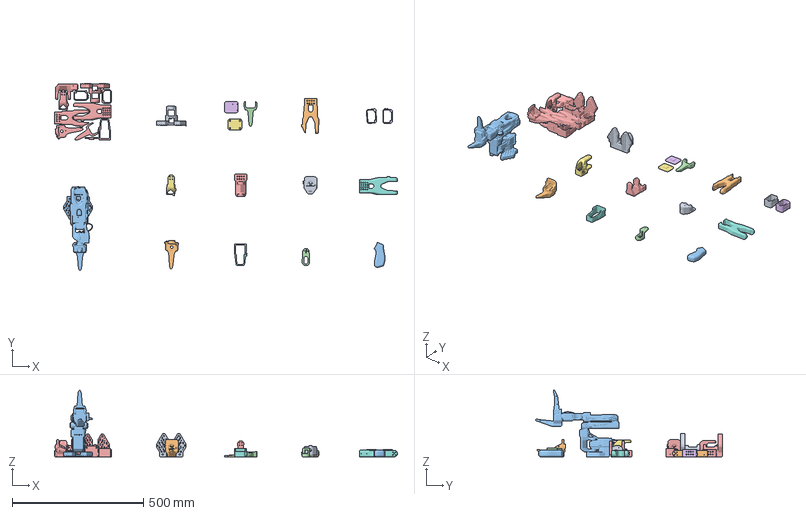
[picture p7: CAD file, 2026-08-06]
3d/3mf/Ender_Follower_SO101_sz102.3mf
1304.6 x 710.6 x 253.4 mm
Wrist_Roll_SO101.stl
Under_arm_SO101.stl
Handle_SO101.stl
Trigger_SO101.stl
Rotation_Pitch_SO101.stl
Motor_holder_SO101_Wrist.stl
Wrist_Roll_Pitch_SO101.stl
Base_motor_holder_SO101.stl
Motor_holder_SO101_Base.stl
Wrist_Roll_Follower_SO101.stl
SO101 Assembly.stl
Moving_Jaw_SO101.stl
Ender_Follower_SO101.stl
Seeedstudio_Mounting_Plate_SO101.stl
WaveShare_Mounting_Plate_SO101.stl
Upper_arm_SO101.stl
Base_SO101.stl

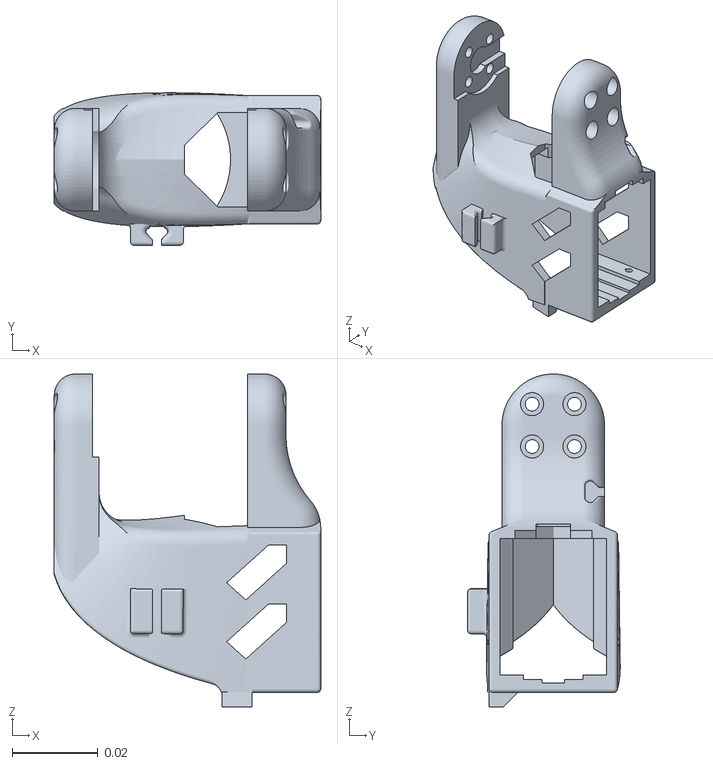
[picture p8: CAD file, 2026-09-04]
robotic_arm_ws/src/robotic_arm_description/meshes/wrist_roll_pitch_so101_v2.stl
0.0623 x 0.0357 x 0.0778

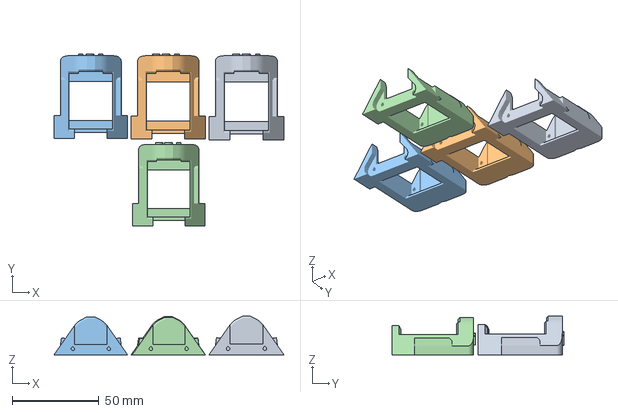
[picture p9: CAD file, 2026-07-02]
3d/3mf/test_Base_SO101.3mf
132.2 x 98.9 x 22.2 mm
Base_SO101.stl x 4

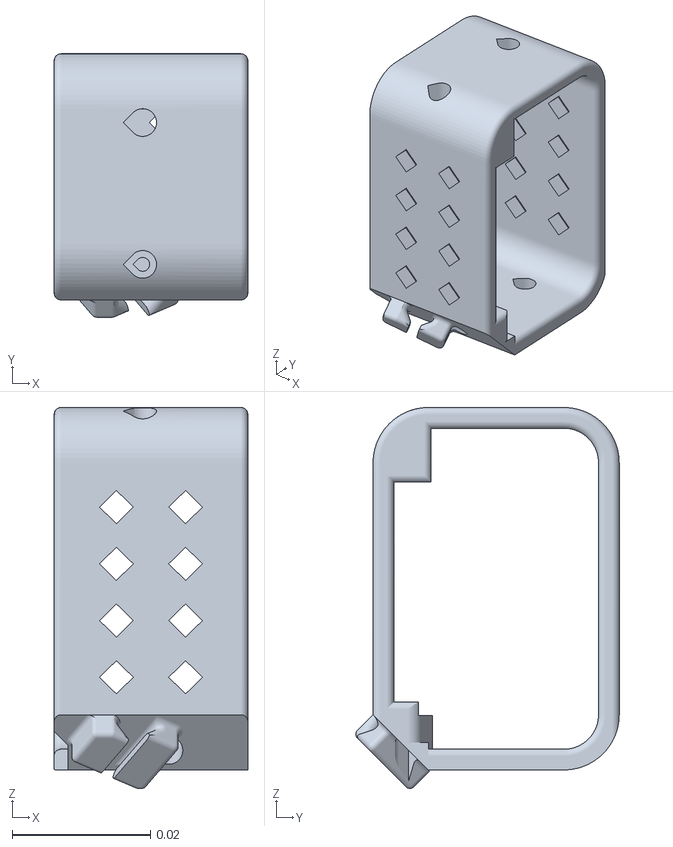
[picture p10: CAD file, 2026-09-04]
robotic_arm_ws/src/robotic_arm_description/meshes/motor_holder_so101_base_v1.stl
0.028 x 0.0381 x 0.0551

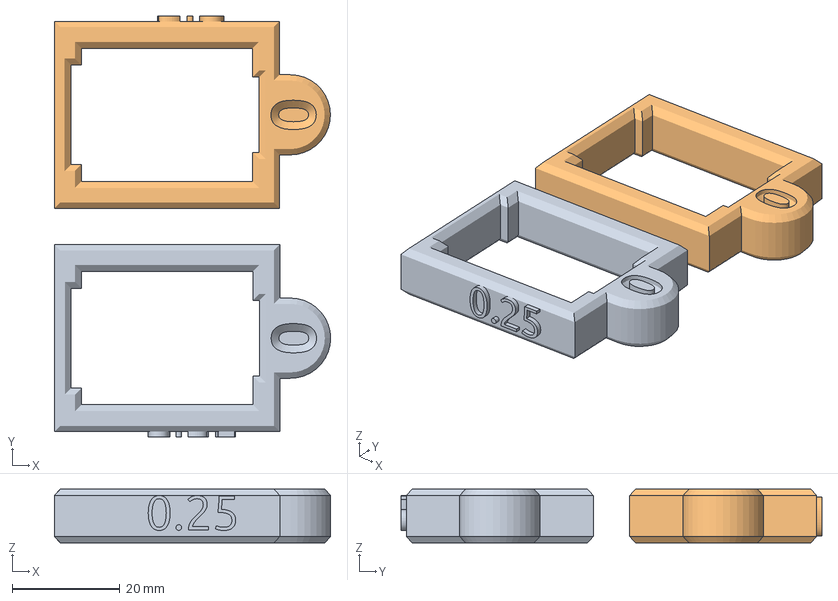
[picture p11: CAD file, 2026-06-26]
3d/3mf/test_gauges_2.3mf
51.3 x 78.1 x 10.0 mm
Gauge_0.STL x 2

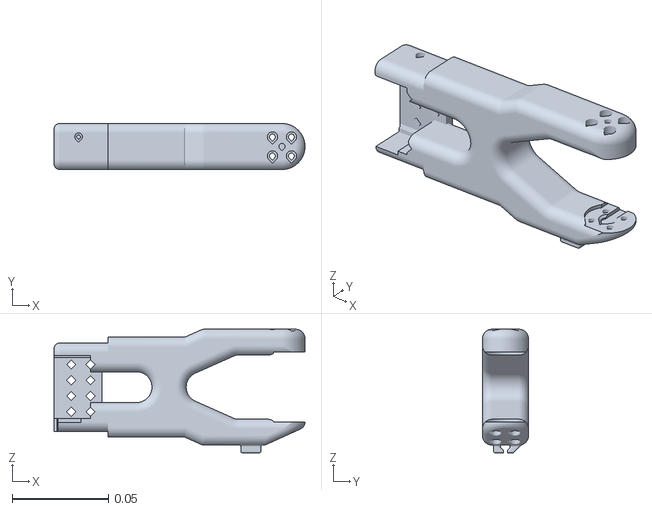
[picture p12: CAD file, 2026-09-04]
robotic_arm_ws/src/robotic_arm_description/meshes/under_arm_so101_v1.stl
0.131 x 0.024 x 0.0644

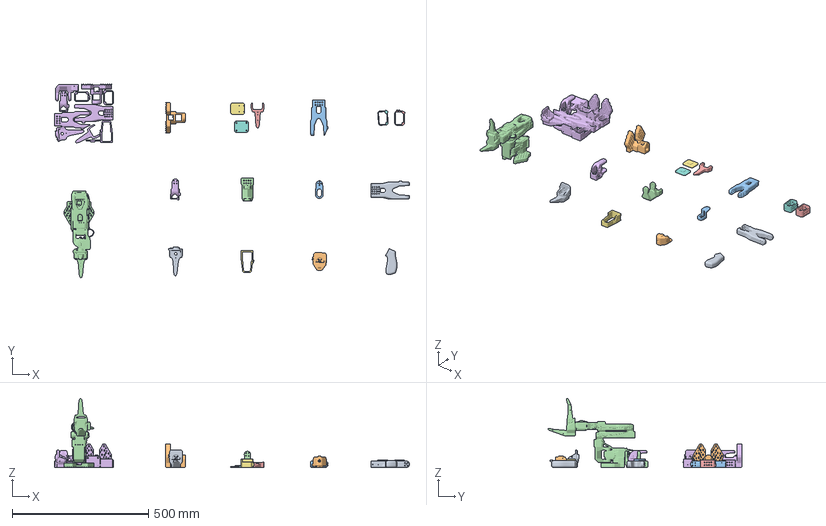
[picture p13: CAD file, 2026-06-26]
3d/3mf/Ender_Follower_SO101.3mf
1303.2 x 710.6 x 253.4 mm
Handle_SO101.stl
Wrist_Roll_SO101.stl
Trigger_SO101.stl
Rotation_Pitch_SO101.stl
Motor_holder_SO101_Wrist.stl
Wrist_Roll_Pitch_SO101.stl
Base_motor_holder_SO101.stl
Motor_holder_SO101_Base.stl
Wrist_Roll_Follower_SO101.stl
Base_SO101.stl
Under_arm_SO101.stl
SO101 Assembly.stl
Moving_Jaw_SO101.stl
Ender_Follower_SO101.stl
Seeedstudio_Mounting_Plate_SO101.stl
WaveShare_Mounting_Plate_SO101.stl
Upper_arm_SO101.stl

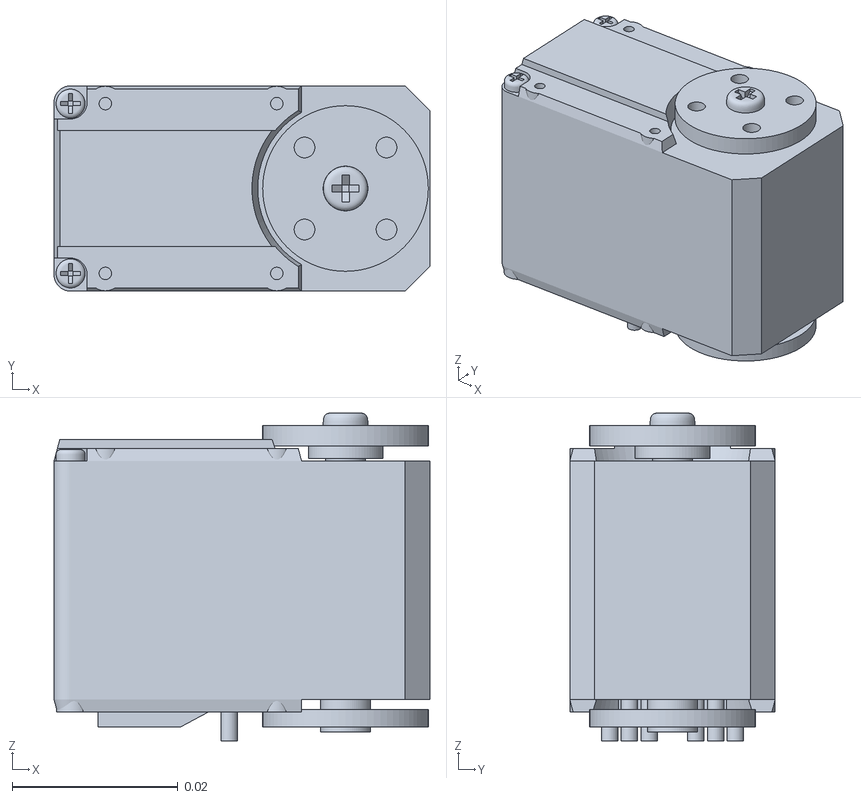
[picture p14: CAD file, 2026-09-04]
robotic_arm_ws/src/robotic_arm_description/meshes/sts3215_03a_v1.stl
0.0454 x 0.0248 x 0.0396

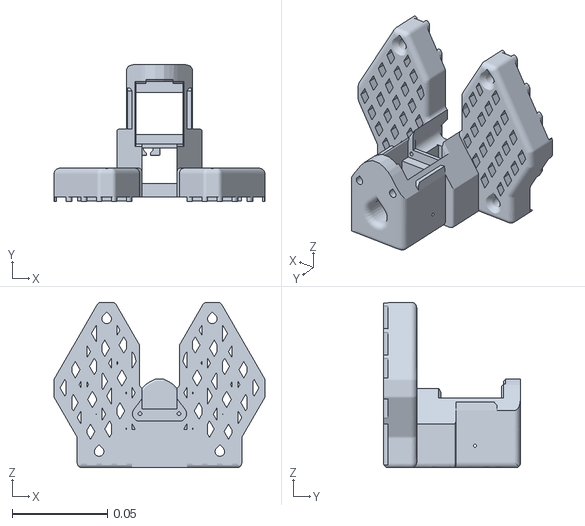
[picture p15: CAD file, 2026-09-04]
robotic_arm_ws/src/robotic_arm_description/meshes/base_so101_v2.stl
0.111 x 0.072 x 0.087

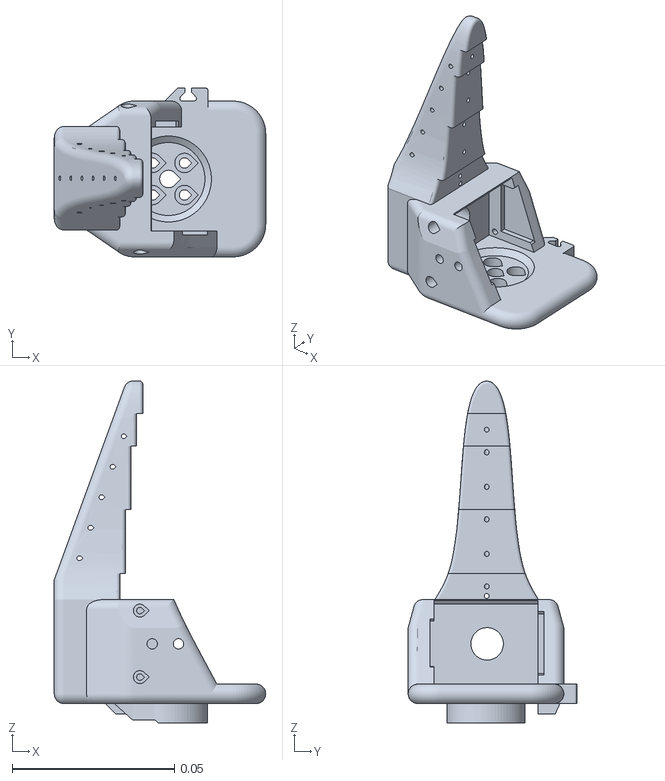
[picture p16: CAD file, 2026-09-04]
robotic_arm_ws/src/robotic_arm_description/meshes/wrist_roll_follower_so101_v1.stl
0.0652 x 0.052 x 0.105

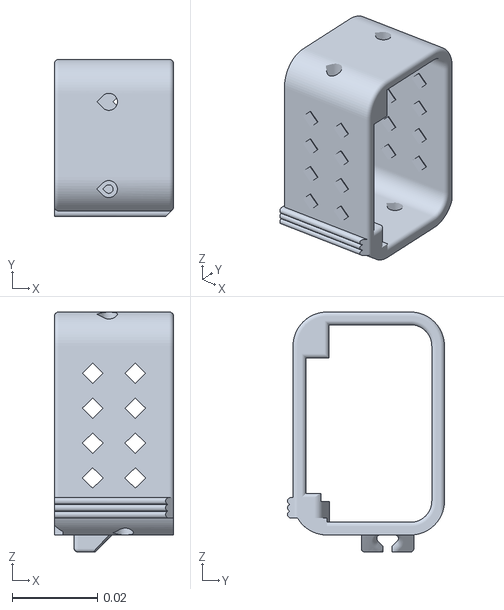
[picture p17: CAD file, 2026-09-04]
robotic_arm_ws/src/robotic_arm_description/meshes/motor_holder_so101_wrist_v1.stl
0.028 x 0.0369 x 0.0564

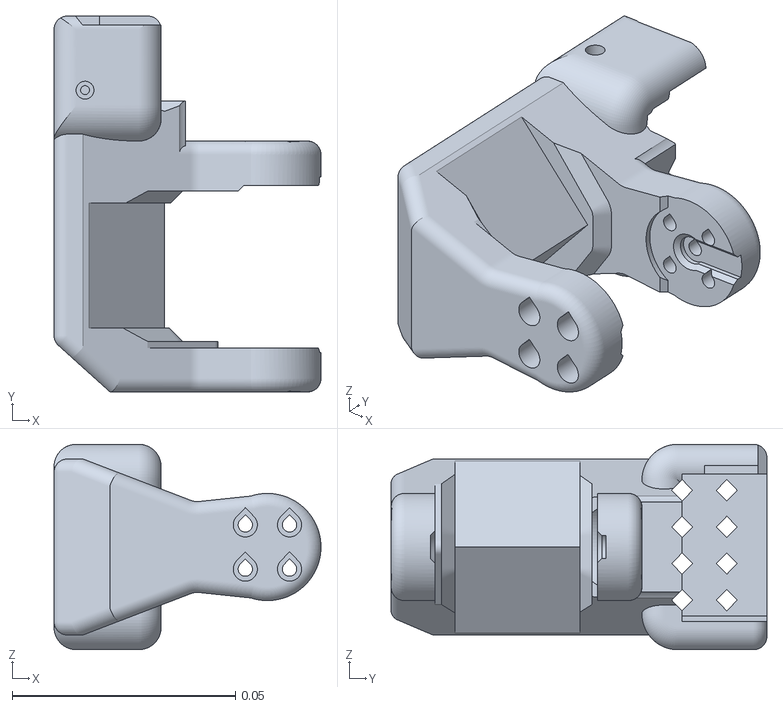
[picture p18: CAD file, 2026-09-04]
robotic_arm_ws/src/robotic_arm_description/meshes/rotation_pitch_so101_v1.stl
0.0598 x 0.0842 x 0.046

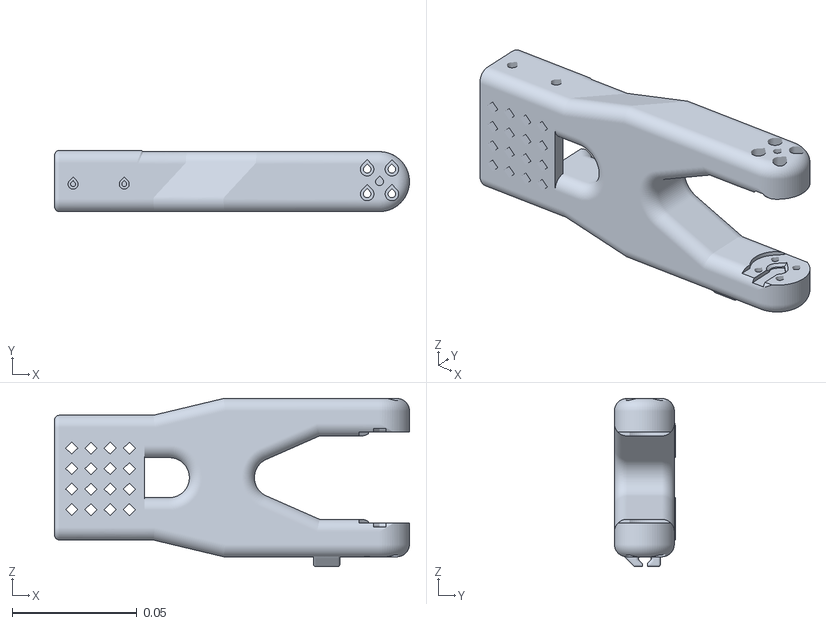
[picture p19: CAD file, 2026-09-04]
robotic_arm_ws/src/robotic_arm_description/meshes/upper_arm_so101_v1.stl
0.142 x 0.0245 x 0.0673

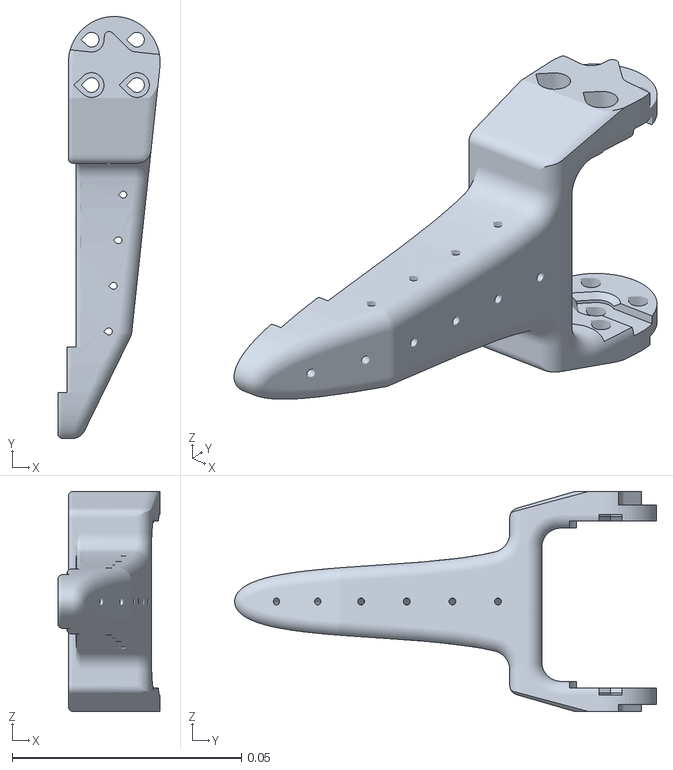
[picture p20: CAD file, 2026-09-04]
robotic_arm_ws/src/robotic_arm_description/meshes/moving_jaw_so101_v1.stl
0.0223 x 0.092 x 0.048

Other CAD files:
robotic_arm_ws/src/robotic_arm_description/meshes/sts3215_03a_no_horn_v1.stl
robotic_arm_ws/src/robotic_arm_description/meshes/waveshare_mounting_plate_so101_v2.stl
robotic_arm_ws/src/robotic_arm_description/meshes/base_motor_holder_so101_v1.stl

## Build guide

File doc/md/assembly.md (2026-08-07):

# Fabricación de brazo robótico RO-101

## 1. Impresión de piezas en PLA
|ID|Pieza|Material|Tiempo de impresión|Cantidad de filamento utilizado|Notas|
|--|-----|---|---|-----|
|1|Base|PLA|5h 8m|74g|Imprimí varias 4 veces este modelo hasta dar con el tamaño que permitía insertar correctamente los servomotores. |
|2|Moving Jaw|PLA|1h 33m|26g||
|3|Under arm|PLA|2h 40m|43g||
|4|Motor holder|PLA|1h 47m|25g||
|5|Wrist Roll Pitch|PLA|2h 43m|31g||
|6|Rotation Pitch|PLA|1h 44m|30g||
|7|Wrist Roll|PLA|2h 13m|27g||
|8|Upper arm|PLA|2h 38m|50g||
|9|Wrist Roll Follower|PLA|2h 15m|32g||
|10|Base motor holder|PLA|1h 6m|18g||

> Todos los modelos descritos arriba fueron impresos con un tamaño de 102% respecto de su tamaño original para que entraran los actuadores que tengo.

- Los modelos fueron descargados de aquí: [https://github.com/TheRobotStudio/SO-ARM100](https://github.com/TheRobotStudio/SO-ARM100)
- Los modelos redimensionados se encuentran en [BrazoRobotico/3d/g_codes/scale_102](BrazoRobotico/3d/g_codes/scale_102)
- La impresora utilizada fue: [Creality Ender-3 V3 SE](https://www.creality.com/products/creality-ender-3-v3-se)

El tiempo total de impresión fue de: **23h 47m**

El total de filamento utilizado fue de: **356g**

## 2. Configuración de motores
1. [How to Use the ST3215 Servo Motor](https://www.youtube.com/watch?v=T5T7qCg4pGE)
2. [https://www.waveshare.com/wiki/ST3215_Servo](https://www.waveshare.com/wiki/ST3215_Servo)
3. [https://www.waveshare.com/wiki/Bus_Servo_Adapter_(A)](https://www.waveshare.com/wiki/Bus_Servo_Adapter_(A))

### Instalar dependencias de python
Según el video 1 del apartado anterior, una vez descargado [STServo_Python.zip](https://files.waveshare.com/wiki/Bus_Servo_Adapter_A/STServo_Python.zip), hay que:

1. Crear un entorno virtual. Tengo que estar parado en */BrazoRobotico/STServo_Python
```bash
python3 -m venv stservo-env
```

2. Activarlo.
```bash
source stservo-env/bin/activate
```

3. Instalar requerimientos
```bash
pip install -r requirements.txt
```
4. Escribir servos. Usar para esto los scripts de la carpeta sms_sts.
5. Para empezar usare el sms_sts/read_write.py. Dentro de este archivo hay que cargar el puerto USB que se va a utilizar.  Ojo! Lo conectaré via USB C, NO mediante UART. Esto es importante porque cambia la posición del jumper en la placa driver de los servos. Para USB hay que usar el jumper en la posición B.
6. Primero hay que conectar la placa driver al motor. Luego, hay que conectar la fuente de 12V a la placa driver y por ultimo el cable USB.
   1. Lo que hice primero fue conectar la fuente de 12 V a la red electrica y verifique con el multimetro la salida: 12.3V.
   2. Luego, conecte la fuente a la placa sin el motor y validé que en los pines de alimentación tenia 12.3V.
   3. Luego, desconecte la alimentacion, conecte el motor y volvi a conectar la alimentacion. En el motor se encendio un led rojo indicando que está energizado.
   4. Luego, conecte el cable USB C a la placa.
   5. Por último conecte el cable USB a la PC.
7. Para identificar el puerto USB
   1. En Windows: [System.IO.Ports.SerialPort]::GetPortNames()
   2. En Linux: ls /dev/ttyUSB*
      1. Cuando ejecuté esto en mi computadora no encontre nada. Tuve que ejecutar ls /dev/tty* y recién ahí encontré puertos. Comparé lo que arrojaba dicho comando con y sin la placa conectada y encontré que con la placa conectada aparece /dev/ttyACM0 
8. Configurar puerto en archivo read_write.py
9. Ejecutar python3 read_write.py. A continuación comparto los logs.
    ```bash
    ❯ python3 read_write.py
    Succeeded to open the port
    Succeeded to change the baudrate
    Press any key to continue! (or press ESC to quit!)
    [ID:001] GoalPos:0 PresPos:1074 PresSpd:-1150
    [ID:001] GoalPos:0 PresPos:1074 PresSpd:-1150
    [ID:001] GoalPos:0 PresPos:1073 PresSpd:-1150
    [ID:001] GoalPos:0 PresPos:1072 PresSpd:-1150
    [ID:001] GoalPos:0 PresPos:1072 PresSpd:-1150
    [ID:001] GoalPos:0 PresPos:1071 PresSpd:-1150
    [ID:001] GoalPos:0 PresPos:1069 PresSpd:-1150
    [ID:001] GoalPos:0 PresPos:1068 PresSpd:-1150
    [ID:001] GoalPos:0 PresPos:1068 PresSpd:-1150
    ```
    En el siguiente video se puede ver el resultado:
    [mover-servo](../videos/mover-servo.mp4)
### Configurar ID de motores
Los servos vienen con un ID predefinido con valor 1.
Tengo que cambiar el ID de cada uno para que tras ensamblar el brazo, pueda programar cada uno por separado.

Para esto voy a usar el script change_id.py. En el mismo se tiene que configurar el puerto y el nuevo id.

Listo. Configurados los 6 servomotores con ID: 1, 2, 3, 4, 5 y 6.

Se valida su funcionamiento en modo bus en este video: [mover servos](../videos/mover-servos.mp4)

## 3. Ensamblado
- [LeRobot SO-ARM101 Robotic Arm - Assembly and Setup Guide\](https://www.youtube.com/watch?v=70GuJf2jbYk)
- Ensamblado de brazo robótico seguidor completo. El brazo robótico lider no entra en este proyecto.

## 4. Calibración
- [SO101 Arms: Calibration and Motor Configuration](https://www.youtube.com/watch?v=Nhfda8h7e2I)
- [Repositorio de LeRobot](https://github.com/huggingface/lerobot/tree/main)
    - En dicho repositorio se encuentra el script que se usa para calibrar el brazo src/lerobot/scripts/lerobot_calibrate.py
    - A ese escript hay que pasarle:
    ```bash
    lerobot-calibrate \
    --robot.type=so101_follower \
    --robot.port=/dev/tty.usbmodem58760431551 \ # <- The port of your robot
    --robot.id=my_awesome_follower_arm # <- Give the robot a unique name
    ```
    - En mi caso sería:
     ```bash
    lerobot-calibrate \
    --robot.type=so101_follower \
    --robot.port=/dev/ttyACM0 \ 
    --robot.id=blue_follower_arm 
    ```
- Luego, tras ejecutar ese escript hay que hacer lo que hacen en este video: [Ejemplo calibracion](https://huggingface.co/docs/lerobot/so101?calibrate_leader=Command#calibration-video)

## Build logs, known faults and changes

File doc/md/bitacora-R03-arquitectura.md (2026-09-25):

# Bitácora [R03] — Arquitectura ROS2 de la aplicación

_Inicio: 2026-09-25_

## Contexto

Definir la arquitectura ROS2 de la aplicación: paquetes, nodos, interfaces entre ellos (topics, servicios, actions) y diferencias entre simulación y robot real, tomando como base el curso de manipuladores con ROS2.

El objetivo original era solo definir los nodos; se amplió porque el inventario de nodos es una parte de la arquitectura, que también incluye cómo se comunican y qué cambia entre sim y real.

Referencia: `Section9_Build/arduinobot_ws/src` del curso (la sección más completa, con robot real).

## Diagramas de arquitectura

### Vista general (por capas)

```mermaid
flowchart TB
    USER([Usuario])

    subgraph HW[Brazo robotico]
        PANEL[Botonera, LCD y potenciometro]
        ESP[ESP32 - seguridad y control de servos]
        SERVOS[Servos STS3215]
    end

    subgraph PC[Computadora integrada - ROS 2]
        APP[Aplicacion - supervisor, grabaciones y tareas]
        MOTION[Planificacion de movimiento - MoveIt2]
        CTRL[Control - ros2_control]
    end

    USER --> PANEL
    USER -.->|opcional| APP
    PANEL --> ESP
    ESP --> SERVOS
    ESP -->|UART - protocolo propio| CTRL
    CTRL --> ESP
    CTRL -->|eventos de botones| APP
    APP --> MOTION
    MOTION --> CTRL
```

1. El usuario opera el brazo desde la botonera (la consola de Linux es opcional).
2. El ESP32 resuelve lo inmediato y crítico: lee la botonera, maneja los servos y ejecuta la parada de emergencia sin depender de la PC.
3. La computadora integrada (ROS 2) decide: la aplicación elige qué hacer (grabar, reproducir), MoveIt2 planifica cómo moverse y `ros2_control` lo traduce a comandos.
4. Las dos mitades hablan por UART con el protocolo propio (tramas `M`, `E`, `S`, `D`).

### Stack por capas (hardware abajo, aplicación arriba)

```mermaid
flowchart TB
    subgraph L7[7 - Aplicacion]
        SUP[arm_supervisor]
        REC[recording_manager]
        TS[task_server]
        UI[RViz / consola Linux - opcional]
    end

    subgraph L6[6 - Planificacion de movimiento - MoveIt2]
        MG[move_group]
        MPY[MoveItPy]
    end

    subgraph L5[5 - Control - ros2_control]
        JTC[arm_controller y gripper_controller]
        JSB[joint_state_broadcaster]
        RSP[robot_state_publisher]
    end

    subgraph L4[4 - Interfaz de hardware]
        PLUGIN[RoboticArmInterface - plugin C++]
    end

    subgraph L3[3 - Comunicacion]
        UART[UART 115200 - tramas M, E, S, D]
    end

    subgraph L2[2 - Firmware ESP32]
        FW[Estados, parada de emergencia, torque, display]
    end

    subgraph L1[1 - Hardware]
        SERVOS[Servos STS3215]
        PANEL[Botonera, LCD 20x4, potenciometro]
    end

    TS --> MPY
    UI --> MG
    MG --> JTC
    MPY --> JTC
    JTC --> PLUGIN
    PLUGIN --> UART
    UART --> FW
    FW --> SERVOS
    FW --> PANEL
```

De abajo hacia arriba:

1. **Hardware:** servos e interfaz física del usuario.
2. **Firmware ESP32:** lo crítico en tiempo real (parada de emergencia, torque, display).
3. **Comunicación:** protocolo propio por UART.
4. **Interfaz de hardware:** el plugin que traduce entre tramas y ROS.
5. **Control:** `ros2_control` sigue trayectorias y publica el estado de los joints.
6. **Planificación:** MoveIt2 calcula cómo moverse; dos entradas: `move_group` (RViz) y MoveItPy (`task_server`).
7. **Aplicación:** la lógica del proyecto (supervisión, grabaciones, tareas).

Las flechas muestran el camino de un comando de movimiento hacia abajo; la información también sube (posiciones, eventos), detallado en el diagrama de nodos y topics.

### Nodos, topics, actions y servicios (modo real)

Zoom de la caja "Computadora integrada". Borde y flechas punteadas: planificado, sin implementar. Formas: rectángulo = nodo, redondeado = topic, doble borde = action, hexágono = servicio.

```mermaid
flowchart LR
    subgraph CM[controller_manager]
        PLUGIN[RoboticArmInterface - hardware plugin]
        JSB[joint_state_broadcaster]
        ARM[arm_controller]
        GRIP[gripper_controller]
    end
    RSP[robot_state_publisher]
    MG[move_group]
    RVIZ[rviz2 - opcional use_rviz]
    TS[task_server - MoveItPy]
    SUP[arm_supervisor]
    REC[recording_manager]
    ESP[ESP32 - UART M E S D]

    T_JS(["/joint_states"])
    T_RD(["/robot_description"])
    T_TF(["/tf"])
    T_EV(["/esp32/events"])
    T_ST(["/esp32/start"])
    T_DI(["/esp32/display"])
    T_SS(["/arm_supervisor/state"])

    A_ARM[["/arm_controller/follow_joint_trajectory"]]
    A_GRIP[["/gripper_controller/follow_joint_trajectory"]]
    A_MOVE[["/move_action"]]
    A_TASK[["/task_server"]]

    S_REC{{"save, list, get, delete"}}

    ESP -->|serial| PLUGIN
    PLUGIN -->|serial| ESP

    JSB --> T_JS
    T_JS --> RSP
    T_JS --> MG
    T_JS --> TS
    RSP --> T_RD
    RSP --> T_TF
    T_TF --> RVIZ

    RVIZ --> A_MOVE
    A_MOVE --> MG
    MG --> A_ARM
    MG --> A_GRIP
    TS --> A_ARM
    TS --> A_GRIP
    A_ARM --> ARM
    A_GRIP --> GRIP

    PLUGIN -.-> T_EV
    T_EV -.-> SUP
    SUP -.-> T_ST
    T_ST -.-> PLUGIN
    SUP -.-> T_DI
    T_DI -.-> PLUGIN
    SUP -.-> T_SS
    T_SS -.-> TS

    SUP -.->|home, ejecutar grabacion| A_TASK
    A_TASK --> TS
    SUP -.->|cancelar ante parada| A_ARM
    SUP -.-> S_REC
    S_REC -.-> REC

    classDef planned stroke-dasharray: 5 5
    class SUP,REC,T_EV,T_ST,T_DI,T_SS,S_REC planned
```

- Hay dos caminos al movimiento: RViz → `move_action` → `move_group` → controllers, y `task_server` (MoveItPy, planifica en su propio proceso) → controllers directo. Por eso el supervisor cancela **en el controller**: es el único punto común.
- El plugin es la única puerta al ESP32: baja `/esp32/start` y `/esp32/display` a tramas y sube los `E` como `/esp32/events`.
- `/arm_supervisor/state` es un nombre provisorio; los tipos de mensaje se definen junto con las interfaces.

Sintaxis Mermaid conservadora (sin `<-->`, sin flechas encadenadas, clases asignadas aparte) para que renderice en visores con versiones viejas de Mermaid. Ambos diagramas validados con `@mermaid-js/mermaid-cli`.

## Hallazgo: la tarea ya estaba casi resuelta

Al comparar los dos workspaces, casi todos los paquetes del curso ya se habían portado mientras se avanzaba con `[R05]` a `[R11]`. La tarea pasó de "definir desde cero" a **cerrar el inventario**: decidir qué faltantes necesita el brazo y cuáles no.

## Inventario

| Paquete del curso | En `robotic_arm_ws` | Contenido | Decisión |
|---|---|---|---|
| `description` | ✅ `robotic_arm_description` | URDF, launch `display` y `gazebo` | Portado (`[R02]`) |
| `controller` | ✅ `robotic_arm_controller` | Plugin `ros2_control`, `slider_control`, controllers | Portado (`[R09]`) |
| `moveit` | ✅ `robotic_arm_moveit` | `move_group` | Portado (`[R05]`) |
| `remote` | ✅ `robotic_arm_remote` | `task_server` (action server, Python) | Portado (`[R07]`) |
| `firmware` | ✅ `robotic_arm_firmware` | `simple_serial_transmitter` / `receiver` | Portado (`[R10]`) |
| `msgs` | ✅ `robotic_arm_msgs` | Action `RoboticArmTask` | Portado (`[R07]`) |
| `bringup` | ✅ `robotic_arm_bringup` | Launch `simulated_robot` / `real_robot` | Creado en `[R12]` |
| `utils` | ❌ | `angle_conversion` (euler ↔ quaternion como servicio) | No por ahora |
| `remote/alexa_interface` | ❌ | Control por voz (Section 8) | Descartado |
| `cpp_examples` / `py_examples` | — | Ejemplos de aprendizaje | No forman parte del robot |

## Decisiones

### `alexa_interface`: descartado

El control por voz no forma parte del alcance del proyecto.

### `angle_conversion`: no por ahora

Convierte ángulos de Euler (roll, pitch, yaw) a quaternion y viceversa. Hace falta para goals **cartesianos** del efector ("andá a x, y, z con esta orientación"), porque ROS representa orientaciones con quaternions.

Verificado en `robotic_arm_remote/task_server.py`: todas las tareas son **ángulos de joint** (`set_joint_group_positions`), sin poses cartesianas ni quaternions. No hay quien use el servicio.

**Trabajo futuro:** si se agregan tareas del tipo "agarrá el objeto en (x, y, z)" (por ejemplo, con una cámara), vuelve a hacer falta.

### `bringup`: faltaba y se creó

Era el único faltante con valor inmediato: un solo comando que levanta todo el sistema pasando `is_sim` coherente a cada parte. Se resolvió como tarea aparte, `[R12]` (ver `doc/md/bitacora-R12-bringup.md`).

### Nodos de aprendizaje fuera del sistema final

- **`simple_serial_transmitter` / `simple_serial_receiver`** (`[R10]`): no van en el sistema final. Abren el mismo puerto serie que el plugin `RoboticArmInterface`. En Linux dos procesos pueden abrir el mismo `/dev/tty*` sin error: cada byte lo recibe uno solo de los lectores (las tramas `M` llegan partidas) y las escrituras se intercalan. Falla silenciosa ("a veces no responde"). Solo sirven para depurar el ESP32 con el plugin apagado.
- **`simple_lifecycle_node`** (`[R11]`): eliminado de `robotic_arm_remote` (paquete del sistema real). Queda en el commit `370bab1` y documentado en la bitácora de `[R11]`.

## Parada de emergencia y estados del ESP32

### Quién detiene el brazo

La parada la ejecuta el **ESP32**, lo más cerca posible de los servos y sin depender de la PC. Si la parada pasara por ROS (`E` → `read()` → topic → nodo → cancelar → `write()`), la latencia se suma en cada salto, y si algo de la PC está colgado el brazo no para. Después de detener, el ESP32 **informa** a la PC con un evento `E`.

### Botones

| Botón | Acción | Efecto |
|---|---|---|
| 1 — parar/soltar | 1.ª pulsación | Frena y **mantiene torque en todos los servos**: el brazo no cae y no suelta la carga |
| 1 — parar/soltar | 2.ª pulsación | Abre el gripper (liberar la carga a mano) |
| 2 — cortar torque | Pulsación | Corta el torque de los joints del brazo para moverlo a mano (liberar algo atrapado entre eslabones) |

- Botón 1 es una **parada controlada con retención**, no un corte de energía: prioriza no soltar la carga.
- Botón 2 hace caer el brazo por gravedad (con la carga, si la sostiene). Es aceptable para liberar a alguien atrapado, por eso es un botón **dedicado**, no una combinación fácil de apretar sin querer.
- Definición de hardware de los botones: pendiente.

### Máquina de estados

```
DETENIDO ──S──▶ INICIALIZADO ──(home + trabajo con M)──▶ OPERANDO
    ▲                                                        │
    └────────────────── botón 1 / botón 2 ◀──────────────────┘
```

- **Parada enclavada (latched):** en `DETENIDO` el ESP32 **ignora las tramas `M`**. `write()` manda `M` cada ciclo (50 Hz) con el objetivo de la trayectoria en curso; si el ESP32 las obedeciera, el brazo retomaría el movimiento 20 ms después de frenar.
- Solo sale de `DETENIDO` con el comando **`S` (start)**: rearmar tiene que ser una acción deliberada.
- Todas las transiciones de estado se informan a la PC con un `E`.

#### Estado `ENSEÑANZA` (agregado con teach & repeat)

Cuarto estado del ESP32. Es el único estado de la aplicación (R4.1) que cambia el comportamiento del ESP32:

- Corta el torque de los joints del brazo (el usuario lo mueve a mano).
- Mantiene el torque del gripper y hace que siga al **potenciómetro**.
- Sigue informando posiciones a la PC (para capturar waypoints).

Transiciones de entrada y salida de `ENSEÑANZA`: pendientes (junto con el flujo de la botonera).

#### Dos niveles de estados

| Nivel | Dónde vive | Estados | Para qué |
|---|---|---|---|
| Seguridad / hardware | ESP32 | `DETENIDO`, `INICIALIZADO`, `OPERANDO`, `ENSEÑANZA` | Si el brazo puede moverse y cómo se comportan los servos |
| Aplicación (R4.1) | `arm_supervisor` | listo, enseñanza, grabando, guardado, reproduciendo, finalizado, error, detenido | Lo que ve el usuario y la lógica de la tarea |

El ESP32 no necesita saber si algo está "guardado" o "finalizado": esos estados viven solo en el supervisor. Solo "enseñanza" tiene su par en el ESP32, porque cambia qué hacen los servos.

### Comando `S`

```
STX | LEN | S | FS | param_init (opcional) | ETX | LRC
```

- `param_init`: configuración adicional opcional (contenido a definir).
- **Se responde con `E`** (código "inicializado"), no con `S`: la `S` no pide datos, pide un cambio de estado, y todo cambio de estado se informa con `E`. La PC espera ese código con timeout; si no llega, no empieza a mandar `M`.

### Secuencia de operación

1. La PC manda `S` (con `param_init` opcional).
2. El ESP32 responde `E` "inicializado".
3. La PC manda el brazo a **home** antes de empezar el trabajo: el brazo arranca siempre desde una posición conocida (después del botón 2 queda donde lo dejaron a mano).
4. Trabajo normal: `M` ↔ `M`.
5. Botón → el ESP32 frena y manda `E`. La PC cambia de estado y decide qué hacer.
6. Vuelve a esperar `S`.

### Qué hace la PC al recibir el `E` de parada

**Cancelar la trayectoria en curso de inmediato.** Mientras el brazo está detenido, el `joint_trajectory_controller` sigue avanzando y `write()` sigue mandando esos objetivos (el ESP32 los ignora). Al cancelar, el controller sostiene la posición **medida**, que es real porque `read()` usa el feedback de los servos (`[R09]`). Así, después de la `S`, el plan a home parte de donde el brazo realmente quedó y no hay salto.

### Nodo `arm_supervisor`

La lógica de parada, `S` y home va en un **nodo nuevo**, no en el `task_server`:

1. **El `task_server` no es el único que mueve el brazo:** RViz (Plan & Execute) y `slider_control` hablan directo con `move_group` o con los controllers. Si la parada viviera en el `task_server`, un movimiento desde RViz no se cancelaría.
2. **Responsabilidades distintas:** el `task_server` ejecuta tareas; el supervisor vigila el estado del sistema.
3. **Tiene que estar siempre vivo**, aunque el `task_server` no se lance.

| Nodo | Responsabilidad |
|---|---|
| `arm_supervisor` (nuevo) | Máquina de estados del brazo (DETENIDO / INICIALIZADO / OPERANDO). Manda `S` y va a home. Al recibir la parada, cancela la trayectoria activa **del controller** (sin importar quién la mandó). Publica el estado del sistema. Decide cuándo capturar waypoints. **Dueño del display**: publica en `/esp32/display` qué muestra el LCD (conoce el estado de la aplicación y la selección actual). |
| `task_server` | Ejecuta movimientos. Hoy: 7 tareas fijas (0–6). Crece para "ir a home" y "ejecutar una grabación" (recorrer la lista de waypoints que le pasa el supervisor). **Ejecuta, no decide ni guarda:** no lee archivos ni sabe de botones. Consulta el estado y rechaza goals si el brazo no está en OPERANDO. |
| `recording_manager` (nuevo) | Persistencia de grabaciones (waypoints + gripper): servicios `save`, `list`, `get`, `delete`. |

**No es lifecycle node:**

- No toma recursos propios (el puerto lo tiene el plugin): no hay nada que abrir en `on_configure` ni liberar en `on_cleanup`.
- Evita mezclar dos máquinas de estados: la del **brazo** (DETENIDO/INICIALIZADO/OPERANDO) y la del **nodo** (`unconfigured`/`inactive`/`active`).
- Un supervisor desactivable es un riesgo: en `inactive` dejaría de cancelar trayectorias ante una parada.
- Donde sí encaja lifecycle es en el plugin (pendiente de `[R09]`: abrir el puerto en `on_configure`). Reconsiderar si el supervisor llegara a tomar un recurso propio.

### Comunicación plugin ↔ `arm_supervisor`

El puerto serie lo tiene el plugin `RoboticArmInterface`, que no es un nodo: corre dentro del `controller_manager`. El curso no resuelve esto (el plugin del arduinobot no publica ni usa GPIO: no tiene botones ni eventos).

Opciones evaluadas (verificadas en Jazzy):

| | A: topics desde el plugin | B: GPIO + `GpioCommandController` |
|---|---|---|
| Parecido a `[R10]` | Alto (publisher/subscriber como `simple_serial_*`) | Bajo |
| Qué se toca | Solo el plugin | Plugin + xacro (`<gpio>`) + YAML de controllers |
| Formato | Libre (p. ej. `String` con el código) | Solo `double` |
| A cuidar | `RealtimePublisher`: `read()` corre en el loop de tiempo real | Lo resuelve el controller |

**Decisión: opción A** (más simple, patrón conocido, todo contenido en el plugin). B es la más idiomática de `ros2_control`; queda como alternativa si A se complica.

- **Eventos (`E` → supervisor):** en `on_init`, publisher de tiempo real (`realtime_tools::RealtimePublisher`) creado con `get_node()` (`hardware_component_interface.hpp:580` en Jazzy), en un topic tipo `/esp32/events`. `read()` publica cada `E` parseado.
- **Start (supervisor → `S`):** suscripción a un topic tipo `/esp32/start`. El callback solo levanta una **bandera atómica**; `write()` la consume, arma la trama `S` y la manda. La escritura al puerto sigue pasando solo por `write()` y nunca se cruza con una `M`.

### Pendiente

Tabla de códigos de `E`:

| Código | Evento |
|---|---|
| ? | Inicializado (respuesta a `S`) |
| ? | Parada por botón 1 (torque mantenido) |
| ? | Grip liberado (botón 1, 2.ª pulsación) |
| ? | Torque cortado (botón 2) |
| ? | Errores (servo que no responde, trama inválida, …) |

## Teach & repeat (enseñar y repetir)

### Qué piden los requisitos

De `doc/md/requisitos.md`, `tables/PLAN_CSV/REQUERIMIENTOS.csv` y `doc/img/display_y_boyonera.png`:

| Requisito | Qué implica |
|---|---|
| R3.0–R3.2 | Grabar una secuencia durante la enseñanza y reproducirla. `requisitos.md:81` define trayectoria como "secuencia ordenada de posiciones articulares y tiempos asociados". |
| R3.3 / R3.4 | Seleccionar y borrar trayectorias guardadas. |
| R3.5 | Persistencia después de apagar: se guardan en disco del lado de la PC. |
| R4.0 + imagen | LCD 20×4 (HD44780) y botonera GRABAR / SELECCIONAR / REPRODUCIR / BORRAR. La parada va aparte (R5.1). |
| R4.1 | Estados mínimos: listo, enseñanza, grabando, guardado, reproduciendo, finalizado, error, detenido. |
| R5.3 | Posición de referencia (home) antes de reproducir. |
| R6.0 | La "PC" es una **computadora integrada** en el brazo: sin computadora externa en uso normal. |

### Decisión: waypoints + MoveIt (primera etapa)

Los requisitos se escribieron antes de conocer MoveIt. En vez de grabar una trayectoria continua (posiciones + tiempos) y reproducirla directo por el `joint_trajectory_controller`, en la primera etapa se graban **waypoints** y MoveIt planifica entre ellos (programación por waypoints, como muchas teach pendants industriales).

- **Una grabación = lista ordenada de waypoints.** Cada waypoint guarda las posiciones de los joints del brazo y el estado del gripper.
- A favor: reusa MoveIt y el `task_server` (verificados en `[R07]`/`[R12]`); trayectorias suaves y dentro de límites; sin temblores de la mano ni backlash (`[R04]`) grabados; grabación simple (posicionar y apretar).
- En contra: el camino **entre** waypoints lo decide MoveIt, no el usuario. MoveIt solo evita lo modelado en la escena: un obstáculo real no modelado puede chocarse aunque el usuario lo haya esquivado al enseñar. Se resuelve agregando waypoints intermedios.
- La grabación continua queda como mejora futura.
- **Pendiente:** ajustar en `requisitos.md` la definición de trayectoria (hoy incluye "tiempos asociados") para que coincida con lo implementado.

### Gripper: potenciómetro como el slider de `servo_control_ui.py`

En la aplicación real no hay slider (botonera o consola de Linux). Se agrega un **potenciómetro** en el ESP32 que controla la **posición** del gripper, igual que el slider de `servo_control_ui.py`.

- **Al enseñar:** el gripper **mantiene torque** y sigue al potenciómetro; los joints del brazo quedan sin torque para moverlos a mano (igual que `GRIPPER_SERVO_ID` en `servo_control_ui.py:84-86`).
- **Se graba el valor pedido por el potenciómetro, no la posición leída del gripper.**

Hallazgo en `servo_control_ui.py`: `record_position()` (línea 277) devuelve `_last_position`, la posición **leída** (`set_feedback`, línea 284). En el gripper eso es el **punto de contacto** con la pieza: al reproducir, el servo va justo ahí y la fuerza es casi nula (toca sin apretar). La fuerza al enseñar viene de la diferencia entre lo pedido (más cerrado que la pieza) y el contacto; grabando lo pedido, al reproducir vuelve a apretar.

Tradeoffs aceptados:

- La fuerza depende de cuánto se cerró de más respecto de la pieza: si la pieza varía de tamaño, varía el agarre.
- **Protección de sobrecarga del STS3215** (valores por defecto): si la carga supera el **80 %** (registro 36) durante **2 s** (registro 35), el servo baja a **20 %** de torque (registro 34) y puede aflojar el agarre en pleno traslado. Limitar el recorrido útil del potenciómetro o avisar en el display.

Alternativas evaluadas (quedan como mejora futura):

- **B — estado binario + torque limitado:** grabar `abierto`/`cerrado` y cerrar con el registro *Torque limit* (48). Fuerza independiente del tamaño de la pieza. El potenciómetro podría controlar la **fuerza** en vez de la posición.
- **C — corriente:** grabar la corriente del gripper (registro 69, 6.5 mA/unidad, hasta 3250 mA) al enseñar y cerrar hasta alcanzarla al reproducir.

Registros relevantes del STS3215 (`doc/datasheets/ST3215 memory register map-EN.xls`): no hay sensor de fuerza. *Current current* (69) es la mejor estimación (torque ≈ proporcional a la corriente; el datasheet no da la constante, sirve para comparar o hay que calibrar). *Current load* (60) es el duty cycle del control, más indirecto.

### Pendiente

- Botonera: cómo distinguir "marcar un waypoint más" de "terminar y guardar la grabación".
- Transiciones de entrada y salida del estado `ENSEÑANZA` del ESP32.
- Formato y almacenamiento persistente de las grabaciones en la PC.
- **Display (decidido):** la lista de grabaciones llega al LCD por el CID `D`. Cambia su definición: hoy manda el **ID** de un mensaje prearmado en el ESP32; tiene que pasar a llevar **texto** (líneas a mostrar), porque la lista es dinámica. Como el puerto lo tiene el plugin, hace falta un tercer topic (p. ej. `/esp32/display`) que el plugin escuche y convierta en tramas `D`.
  - Payload: `msg1 FS msg2 FS ... FS msgN`, cada mensaje de hasta **15 caracteres** (en un LCD de 20 columnas deja 5 para prefijo `1: ` y cursor `>`).
  - Una pantalla completa (LCD 20×4) son 4 mensajes: payload 4×15 + 3 = 63, LEN 67. No entraba con el tope de LEN = 64 (payload máx. 60); **se subió el tope a 128** (`kMaxLen` en el plugin y en el firmware). Es un límite de cordura del parser: subirlo no rompe nada. A 115200, ~130 bytes ≈ 11 ms, y `D` solo se manda al cambiar la pantalla.
  - Mensajes en **ASCII imprimible**: no pueden contener `0x02`, `0x03` ni `0x1C` (romperían la trama), y el ROM del HD44780 no tiene `ñ` ni tildes en las posiciones estándar.
- **Quién graba (decidido):** el `arm_supervisor` decide cuándo capturar un waypoint (orquestación, ya escucha los `E`); un nodo nuevo y **aparte**, `recording_manager`, guarda/lista/lee/borra grabaciones en disco con servicios (`save`, `list`, `get`, `delete`). Alineado con R6.1 (módulos separados: grabación, gestión, reproducción…) y permite cambiar el formato de almacenamiento sin tocar la lógica de estados. Tradeoff: un nodo más para lanzar y mantener. Pendiente: formato del archivo y definición de los servicios.
- Ajustar la definición de trayectoria en `requisitos.md`.

### RViz opcional (`use_rviz`)

`moveit.launch.py` lanza RViz siempre. En modo real la computadora va integrada en el brazo (R6.0), probablemente sin monitor: RViz sobra o falla sin pantalla. Se agrega un argumento `use_rviz`:

- `simulated_robot.launch.py`: `use_rviz:=True` (en simulación siempre se quiere ver el brazo).
- `real_robot.launch.py`: `use_rviz:=False`; se activa a mano si se conecta una pantalla.
- Operación desde la consola de Linux (`ros2 action send_goal`, etc.) no necesita RViz.

Pendiente de implementar.

## Nodos del sistema

| Nodo | Paquete | Rol |
|---|---|---|
| `robot_state_publisher` | `controller.launch.py` (real) / `gazebo.launch.py` de `description` (sim) | Publica las TF a partir del URDF y `/joint_states` |
| `controller_manager` + plugin `RoboticArmInterface` | `controller.launch.py` (real) | Habla con el ESP32 por puerto serie (tramas `M`). En sim, el `controller_manager` lo aporta el plugin `gz_ros2_control` dentro de Gazebo |
| `joint_state_broadcaster`, `arm_controller`, `gripper_controller` | `controller` | Controllers de `ros2_control` |
| `move_group` | `moveit` | Planificación y ejecución de trayectorias |
| `task_server` | `remote` | Action server que expone tareas predefinidas sobre MoveIt2 |
| `slider_control` | `controller` | Control manual por sliders (pruebas) |

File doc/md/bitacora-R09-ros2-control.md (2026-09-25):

# Bitácora [R09] — Plugin `ros2_control` en C++ para el brazo real

_Inicio: 2026-09-25_

## Contexto

Implementar en C++ el plugin `ros2_control` (`hardware_interface::SystemInterface`) para el brazo real. La comunicación es directa por puerto serie, reusando la lógica de `STServo_Python`, y la interfaz tiene que quedar reemplazable más adelante por una variante con ESP32 (ver `[E07]`).

Depende de `[R05]` (MoveIt2). Se apoya en lo visto en:
- `[R10]`: nodos puente topic ↔ puerto serie.
- `[R11]`: ciclo de vida de nodos (estados y transiciones).

## Referencia

Curso Udemy "Robotics and ROS 2 - Learn by Doing: Manipulators":

```
/home/ezequiel/cursos/Robotics-and-ROS2-Manipulators/Robotics-and-ROS-2-Learn-by-Doing-Manipulators/Section9_Build/arduinobot_ws/src/arduinobot_controller
```

Archivos de referencia:
- `include/arduinobot_controller/arduinobot_interface.hpp`
- `src/arduinobot_interface.cpp`
- `arduinobot_controller.xml` (descripción del plugin para `pluginlib`)

## Arquitectura

```
PC (ROS2, plugin ros2_control) <-Serial-> ESP32 <-UART-> Driver / Servos STS3215
```

El ESP32, además de manejar los servos, maneja un **display** (mensajes prearmados, seleccionados por ID) y **botones** (eventos que se informan a la PC).

### Túnel vs protocolo propio

Se descartó el ESP32 como túnel puro (reenviar a los servos lo que llega de la PC). Cuando por el mismo enlace viajan dos cosas distintas (servos y display/botones), el receptor necesita distinguirlas: hace falta un framing con identificador de canal, o sea, un protocolo. Mejor diseñarlo desde el principio.

Esto responde `[E07]`: con display y botones, conviene desacoplar la gestión del driver al ESP32.

## Protocolo PC ↔ ESP32 (decidido)

Basado en el protocolo de `[E05]` (`firmware/arduino-uart-test/send_cmd.py`).

```
STX | LEN | CID | FS | payload | ETX | LRC
```

| Campo | Formato | Descripción |
|---|---|---|
| `STX` | `0x02` | Inicio de trama |
| `LEN` | 4 dígitos ASCII decimal | Largo de **CID + FS + payload + ETX + LRC** (sin contarse a sí mismo ni al STX) |
| `CID` | 1 char ASCII | Identificador de comando |
| `FS` | `0x1C` | Separa el CID del payload |
| `payload` | ASCII | Depende del CID |
| `ETX` | `0x03` | Fin de trama (verificación extra para resincronizar) |
| `LRC` | 1 byte | XOR de **LEN + CID + FS + payload + ETX** (todo menos STX) |

Ejemplo: `CID=D` con payload `"07"` → `LEN = "0006"` (`D` + FS + `07` + ETX + LRC).

Largo total de la trama desde STX = `1 + 4 + LEN`. Se incluyen ETX y LRC en LEN para que el parser calcule el fin de trama sin sumar la cola fija.

**FS después del CID:** el CID es de 1 char en posición fija, así que el FS no es estrictamente necesario (el parser podría leerlo por posición). Se agrega igual para poder partir toda la trama con un solo `split(FS)` y dejar abierta la puerta a CIDs de más de un char. Costo: 1 byte por trama.

### CID

| CID | Significado | Dirección | Payload |
|---|---|---|---|
| `M` | Motores / movimiento | PC → ESP32 | Posición objetivo de cada joint: `j1 FS j2 FS ... FS j6` |
| `M` | Motores / movimiento | ESP32 → PC | Posición actual de cada joint, mismo formato |
| `D` | Display | PC → ESP32 | ID de mensaje de una tabla prearmada en el ESP32 |
| `E` | Eventos / errores | ESP32 → PC | ID de evento de botón o de error |

`FS` = `0x1C` (mismo separador que en `[E05]`).

### Unidades de `M`: miliradianes

Se usan **unidades físicas** y no counts, para que el código ROS2 no dependa del servo usado. Los counts son específicos del STS3215 (4096 por vuelta, cero en 2048); el ESP32 es la única capa que conoce el hardware y hace la conversión mrad ↔ counts.

- Formato: **ancho fijo con signo**, 5 chars (`+1571`, `-0785`). Rango ±π → −3142 … +3142.
- Resolución: 1 mrad = 0.057°, más fino que 1 count del STS3215 (0.088°, ver `STServo_Python/calibrate-arm.py`). No se pierde precisión.

Largo de trama `M` (6 joints):

| Unidad | Chars por joint | Trama | Tiempo a 115200 (8N1, ~87 µs/byte) |
|---|---|---|---|
| Counts | 4 | 38 bytes | ~3.3 ms |
| Miliradianes | 5 | 44 bytes | ~3.8 ms |

La diferencia (~0.5 ms) es despreciable frente a un ciclo de 20 ms (loop a 50 Hz).

## Feedback (decidido)

### Modelo request/response

La PC manda `M` (objetivo); el ESP32 escribe a los servos, lee sus posiciones y responde con `M` (posición actual).

- **Un solo maestro**: la PC marca el ritmo. Con streaming periódico del ESP32, si la PC se atrasa se acumulan mensajes viejos en la cola (como en `[R11]`).
- **Bus de servos half-duplex**: el ESP32 no puede escribir y leer a la vez; request/response ordena solo: escribir → leer → responder.
- **Detección de fallas**: si no llega la respuesta, algo se cortó.

`read()` de `ros2_control` no puede bloquear: `write()` manda `M` en el ciclo N y `read()` del ciclo N+1 lee sin bloquear la respuesta ya llegada. Latencia: un ciclo (20 ms a 50 Hz).

Los eventos `E` son asíncronos: el ESP32 los manda cuando ocurren. El parser de la PC tiene que aceptar cualquier CID en cualquier momento.

## Diseño de `write()` (decidido)

### Sin early return: mandar `M` en todos los ciclos

El `write()` del curso no manda nada si los comandos no cambiaron. Con request/response eso rompe el feedback: sin `M` no hay respuesta, y `read()` se queda sin posición actualizada mientras el brazo está quieto (aunque alguien lo empuje o el gripper choque). Además, "no hay respuesta" deja de servir para detectar una desconexión.

Costo de mandar siempre: 44 bytes × 50 Hz = 2200 B/s, menos del 20 % de lo que da 115200 baudios (~11520 B/s). Mandar el mismo objetivo repetido no afecta al servo.

Al sacarlo, `prev_position_commands_` deja de tener uso.

### Sin offsets ni inversiones en la PC

Se eliminan las cuentas del curso (`(pos + π/2) * 180/π`, `180 - ...` en el shoulder), que compensaban el montaje de los servos del arduinobot. La PC manda el ángulo del joint en mrad tal cual; toda la calibración de hardware vive en el ESP32.

### Conversión y formato de cada joint

1. `rad * 1000` → `std::lround` (redondeo al más cercano; `static_cast<int>` trunca hacia cero, con error de hasta 1 mrad y sesgado).
2. `std::clamp` a ±3142, con `RCLCPP_WARN` si recorta (un valor fuera de ±π indica un bug más arriba). Sin clamp, `+12000` daría 6 chars y rompería la trama.
3. `snprintf` con `%+05ld`: `+` fuerza el signo, `0` rellena con ceros, `5` es el ancho **incluyendo el signo** (`-785` → `-0785`, `1571` → `+1571`). `%ld` porque `lround` devuelve `long`.

Pérdida por redondeo: máx 0.5 mrad ≈ 0.029°, unas 3 veces menor que la resolución del STS3215 (2π/4096 ≈ 1.53 mrad ≈ 0.088°). El límite es el servo, no la trama.

Joints separados por `FS` (`0x1C`).

## Diseño de `read()` (decidido)

### Lectura sin bloqueo

El puerto entrega bytes, no tramas: puede llegar media trama y el resto en el ciclo siguiente. Los bytes se acumulan en `rx_buffer_`, **miembro de la clase** (no global en el namespace anónimo): es estado de cada puerto, no se comparte entre instancias y se limpia en `on_activate`.

Trampa de LibSerial (`/usr/include/libserial/SerialPort.h`): en `Read(str, n, msTimeout)`, **`msTimeout = 0` bloquea** hasta recibir los `n` bytes. Si el ESP32 no responde, se congela el loop de `ros2_control`. Solución:

1. `GetNumberOfBytesAvailable()` → `n`. Si `n == 0`, no llamar a `Read()`.
2. `Read()` de exactamente `n` bytes (ya están en el buffer del SO, vuelve al instante) a un string local.
3. Agregar ese string a `rx_buffer_`.

### Parseo y resincronización

Hay dos formas de no tener trama válida: **inválida** (se descarta) e **incompleta** (se espera; descartarla rompería una trama buena).

1. Descartar lo que haya antes del primer STX. Sin STX → vaciar el buffer.
2. No llegaron los 4 bytes de LEN → salir y esperar al próximo `read()`.
3. LEN no son 4 dígitos ASCII o está fuera de rango (mín. 4 = CID + FS + ETX + LRC; máx. 128) → descartar 1 byte, volver a 1.
4. No está la trama completa (`1 + 4 + LEN` bytes) → salir y esperar.
5. ETX no está en su posición o el LRC no coincide (XOR de LEN hasta ETX, sin STX ni el LRC) → descartar 1 byte, volver a 1.
6. Trama válida → procesarla, sacarla del buffer, volver a 1.

- **Descartar 1 byte y no la trama entera**: el LRC puede valer `0x02` y pasar por STX. Si se descarta todo, se pierde la trama real que empezaba adentro.
- **Tope de LEN = 128** (era 64; subido en `[R03]` para que entre una pantalla completa de LCD en una trama `D`: 4 mensajes de 15 chars → payload 63, LEN 67): sin él, un LEN corrupto (`9039`) haría esperar miles de bytes y las tramas buenas quedarían atrapadas. No es parte del formato (LEN es simétrico en ambas direcciones) sino un límite de cordura del parser. La trama más larga esperada es una `M` de 6 joints (LEN = 39); 64 deja margen para más joints o campos.
- **Loop hasta vaciar**: puede haber varias tramas por ciclo (un `E` + una `M`, o dos `M` si el loop se atrasó). Procesar una por llamada acumula latencia (como la cola de `[R11]`). Si llegan varias `M`, gana la última.

### Payload de `M` (respuesta)

La PC no ve el formato de los servos (binario Feetech, counts): el ESP32 convierte counts → mrad y responde con el mismo formato que la `M` de `write()`.

- Cantidad de campos = `position_states_.size()`.
- Cada campo: 5 chars, signo `+`/`-` y 4 dígitos.
- Si un campo falla, se descarta la trama **entera** y `position_states_` conserva los valores anteriores (nunca actualizar a medias).
- Conversión: `mrad / 1000.0` (con `1000` entero, `1571 / 1000` daría `1`).

## Pendientes

- [ ] Mover la apertura del puerto serie de `on_activate` a `on_configure` (ver `[R11]`). Por ahora se sigue la estructura del curso.
- [x] `write()`: reemplazar el protocolo de texto del curso (`b090,s090,...`) por tramas `M`.
- [x] `read()`: usar la posición real informada por los servos en vez de lazo abierto.
- [ ] Detectar cuando el ESP32 deja de responder: hoy `read()` conserva la última posición sin avisar (ver "Detección de fallas" en el modelo request/response).

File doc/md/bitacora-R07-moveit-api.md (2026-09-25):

# Bitácora [R07] — Implementar API para manejar MoveIt2

_Inicio: 2026-09-18_

## Contexto

Implementación de un `task_server` (Action Server propio) que expone MoveIt2 como una API programática, en vez de operar el brazo solo desde RViz. Basado en el ejemplo del curso Udemy en `Section7_Application/arduinobot_ws` (`arduinobot_remote/task_server.py`), que combina:
- El patrón de Actions estudiado en [[project_r06_actions_progress]] (propia interfaz `.action`, no la de MoveGroup directamente).
- `MoveItPy` para planificar/ejecutar (visto en `simple_moveit_interface.py`).

Depende de [R05] (MoveIt2 configurado) y [R06] (Actions).

## MoveGroupInterface (C++) vs MoveItPy (Python)

Verificado contra la documentación oficial de MoveIt2 (picknik.ai) y el código fuente del curso (`task_server.cpp` vs `task_server.py`):

- **`MoveGroupInterface`** (C++): cliente que habla con el nodo `move_group` (separado, corriendo aparte) vía Actions/Services. Desacoplado.
- **`MoveItPy`** (Python): envuelve `MoveItCpp`, que carga el pipeline de planificación completo **dentro del propio proceso**, saltándose la capa de Action/Service — más rápido pero acopla el nodo con toda la config de MoveIt.

Motivo del split en el curso: `moveit_commander` (el equivalente Python clásico de `MoveGroupInterface`) está deprecado en ROS2; `MoveItPy` es el reemplazo oficial, pero no es un reemplazo 1:1.

**Decisión para este proyecto:** implementar primero calcando el ejemplo del curso con `MoveItPy` (para validar que funciona end-to-end), documentado acá. Alternativa desacoplada (action client propio contra `move_action` de `move_group`) queda pendiente como posible refactor futuro.

**Decisión de lenguaje:** Python, por consistencia con el resto del stack del proyecto (`STServo_Python`, control de servos, scripts ESP32) — no hay necesidad de un loop de control duro en tiempo real que justifique C++.

## Paquetes nuevos creados

### `robotic_arm_msgs` (interfaces)
`ros2 pkg create --build-type ament_cmake robotic_arm_msgs`, con `action/RoboticArmTask.action`:
```
# Goal
int32 task_number
---
# Result
bool success
---
# Feedback
int32 percentage
```
`CMakeLists.txt` necesita `find_package(rosidl_default_generators REQUIRED)` + `rosidl_generate_interfaces(${PROJECT_NAME} "action/RoboticArmTask.action")`. `package.xml` necesita `build_depend rosidl_default_generators`, `depend action_msgs`, `exec_depend rosidl_default_runtime`, `member_of_group rosidl_interface_packages`.

### `robotic_arm_remote` (nodo)
`ros2 pkg create --build-type ament_cmake robotic_arm_remote` (elegido `ament_cmake` + `ament_cmake_python`, no `ament_python` puro, para consistencia con `robotic_arm_controller`).

Estructura: `robotic_arm_remote/robotic_arm_remote/{__init__.py, task_server.py}` + `launch/`.

## Errores de build y causa raíz (para no repetirlos)

1. **`file INSTALL cannot find ".../launch"`** — el `CMakeLists.txt` tenía `install(DIRECTORY launch ...)` pero la carpeta no existía todavía. Crearla antes de buildear si el `CMakeLists.txt` ya la referencia.

2. **`Could not find a package configuration file provided by "robotic_arm_msgs"`** — `colcon` arma el orden de build leyendo las dependencias declaradas en `package.xml` de cada paquete. Si `robotic_arm_remote/package.xml` no tiene `<depend>robotic_arm_msgs</depend>` (o `exec_depend`), colcon no sabe que tiene que esperar a que ese paquete termine, y los buildea en paralelo/desorden.

3. **Copiar CMakeLists de un paquete de referencia mixto (C+++Python) trae basura.** `arduinobot_remote` (el paquete del curso) mezcla `task_server.cpp` y `task_server.py` en el mismo `CMakeLists.txt`. Copiarlo literal para un paquete 100% Python arrastra `find_package(moveit_ros_planning_interface REQUIRED)` (la lib C++ de `MoveGroupInterface`, no usada en Python) y un `install(TARGETS ...)` sin ningún target real (instalaba la librería `task_server` que compilaba `add_library(...)` en el original — acá no existe). Lección: revisar línea por línea qué corresponde a la parte que realmente se está portando, no asumir que "es lo mismo que el de referencia".

## `CMakeLists.txt` / `package.xml` finales de `robotic_arm_remote`

`package.xml`: `buildtool_depend` de `ament_cmake` + `ament_cmake_python`; `exec_depend` de `robotic_arm_msgs`, `action_msgs`, `rclpy`, `moveit_py`. Nota: `moveit_py` no se busca con `find_package` en CMake (no se compila nada contra él) — solo aparece en `package.xml` como `exec_depend`, porque es un paquete Python puro.

`CMakeLists.txt`: `find_package` de `ament_cmake`, `ament_cmake_python`, `robotic_arm_msgs`, `rclpy` — sin `moveit_ros_planning_interface`. `ament_python_install_package(${PROJECT_NAME})` + `install(PROGRAMS ${PROJECT_NAME}/task_server.py DESTINATION lib/${PROJECT_NAME} RENAME task_server)`.

## Cómo se cargan los goals en MoveItPy (joint-space)

Flujo de `goalCallback`:
1. `RobotState(get_robot_model())` — una "foto" del estado completo del robot (modelo cinemático de URDF+SRDF).
2. `set_joint_group_positions("arm", arm_joint_goal)` — rellena esa foto con los ángulos deseados. `"arm"`/`"gripper"` son los planning groups del SRDF; el array de ángulos va **en el mismo orden en que el SRDF lista los joints del group** (`shoulder_pan, shoulder_lift, elbow_flex, wrist_flex, wrist_roll` para `arm`; `gripper` para `gripper`).
3. `set_start_state_to_current_state()` — el plan arranca desde la posición real actual del robot (leída de `joint_states`).
4. `set_goal_state(robot_state=...)` — la foto rellenada en el paso 2 pasa a ser el destino del plan.
5. `plan()` — calcula la trayectoria con el planner configurado (OMPL).

**Los valores son ángulos de joint en radianes, uno por joint (joint-space), NO coordenadas cartesianas ni roll/pitch/yaw.** Cada joint del brazo es `type="revolute"` con `axis xyz="0 0 1"` — una bisagra de 1 solo grado de libertad, como un codo: un ángulo describe su estado completo. Roll/pitch/yaw (3 números) hace falta para describir la orientación de un cuerpo libre en el espacio (ej. la pose cartesiana del end-effector), no la de un joint individual — por eso `set_joint_group_positions` solo pide 1 valor por joint. Importante: esto usa radianes del modelo cinemático (cero = pose "zero" del URDF), un sistema de unidades distinto al de los *counts* crudos (0-4095) que usa `STServo_Python/servo_control_ui.py` — la traducción entre ambos la hace `ros2_control`/el hardware interface, no algo a mano en el `task_server`.

## Pendiente bloqueante — el "0" del modelo no coincide con el "0" físico calibrado

El `group_state name="home"` del SRDF (todos los joints en 0) define el "0" de MoveIt como la pose que resulta de los `<origin>` de cada `<joint>` en el URDF — una elección de modelado, visible cargando el robot en RViz sin comandar nada. Pero la calibración física de los servos (`ZERO_COUNTS=2048` en `STServo_Python/calibrate-arm.py`) se hizo **de forma independiente, sin mirar el modelo** (confirmado con el usuario 2026-09-18). Es decir, el "0 rad" del modelo cinemático y el "0" físico calibrado de los servos **no están garantizados a coincidir**.

**Consecuencia:** un goal planificado con MoveIt (ej. `task_server`, o directamente desde RViz) que en simulación se ve correcto y dentro de límites, puede terminar en una pose física distinta al ejecutarse en el brazo real — con riesgo de forzar un joint contra un tope mecánico aunque el modelo diga que está dentro de rango.

**Mitigación actual:** probar todo en Gazebo/simulación (R02/R05) hasta recalibrar. **No ejecutar `task_server` contra el brazo físico hasta resolver este desacople** — ya sea recalibrando los servos para que coincidan con la pose "home" del URDF, o verificando/ajustando el mapeo en el hardware interface de `ros2_control`.

## Bug encontrado — gripper fuera de límites (no corregido todavía)

`task_number == 0` en el `task_server.py` propio manda `gripper_joint_goal = np.array([-0.7])`, copiado del ejemplo del curso. El joint `gripper` del URDF real (`robotic_arm.urdf.xacro`, línea 405) tiene `<limit lower="-0.174533" upper="1.74533"/>` — `-0.7` está ~4 veces más allá del límite inferior. Viene de copiar el valor de un gripper de 2 joints simétrico del `arduinobot` del curso; el SO-101 tiene 1 solo joint (`moving_jaw`) con rango angosto y asimétrico. **Pendiente: corregir antes de ejecutar en hardware real.**

`task_number == 1` y `2` sí verificados dentro de límites de los 5 joints de `arm`.

### Tabla de límites por joint (verificado contra `robotic_arm.urdf.xacro`)

| Joint | Group | Límite inf. (rad) | Límite sup. (rad) | Límite inf. (°) | Límite sup. (°) |
|---|---|---|---|---|---|
| `shoulder_pan` | arm | -1.91986 | 1.91986 | -110.0° | 110.0° |
| `shoulder_lift` | arm | -1.74533 | 1.74533 | -100.0° | 100.0° |
| `elbow_flex` | arm | -1.69 | 1.69 | -96.9° | 96.9° |
| `wrist_flex` | arm | -1.65806 | 1.65806 | -95.0° | 95.0° |
| `wrist_roll` | arm | -2.74385 | 2.84121 | -157.3° | 162.8° |
| `gripper` | gripper | -0.174533 | 1.74533 | -10.0° | 100.0° |

`gripper` es el único asimétrico y el más angosto de todos (el que rompía `task_number == 0`). `wrist_roll` también es asimétrico, a diferencia de los otros 4 joints de `arm`.

## Bug heredado — `goal_handle.succeed()` incondicional (CORREGIDO)

Igual que en el `task_server.py` de referencia: `goal_handle.succeed()` se llamaba siempre, incluso si `arm_plan_result`/`gripper_plan_result` fallaban (el `else` solo logueaba, no cortaba el flujo). Corregido moviendo `result = RoboticArmTask.Result()` antes del `if`, seteando `result.success = True/False` en cada rama, y llamando `goal_handle.succeed()` dentro del `if` y `goal_handle.abort()` dentro del `else`. Ahora el estado del Action y el contenido del `Result` quedan consistentes en los dos casos.

## Segundo bug encontrado en la corrección de valores — `elif` duplicados

Al reescribir los `task_number` con los valores medidos en Gazebo, quedaron **tres `elif` distintos comparando contra el mismo número** (`== 4` repetido tres veces para las tareas "levanto y traslado", "roto a posición b" y "suelto en posición b"). En un `if/elif`, solo se ejecuta el primero que matchea — las otras dos ramas quedaban como código muerto, sin dar ningún error. Corregido renumerando a `4`, `5`, `6`.

## Bloqueadores de lanzamiento encontrados y corregidos

1. **Mismatch de nombre de ejecutable**: `CMakeLists.txt` instala el script con `RENAME task_server` (sin `.py`), pero `remote_interface.launch.py` inicialmente pedía `executable="task_server.py"` (con extensión) — `ros2 launch` fallaba con "executable not found". Corregido a `executable="task_server"`.
2. **Faltaba `robotic_arm_moveit/config/planning_python_api.yaml`**: referenciado por `.moveit_cpp(file_path="config/planning_python_api.yaml")` en el launch, no existía. Creado con `pipeline_names: ["ompl"]` y `plan_request_params` (mismo contenido que el de referencia).

## R07 completada — verificado end-to-end en Gazebo

Secuencia de prueba, en 3 terminales + 1 para mandar goals:

```bash
# Terminal 1 — Gazebo + robot
ros2 launch robotic_arm_description gazebo.launch.py

# Terminal 2 — controladores ros2_control (joint_state_broadcaster, arm_controller, gripper_controller)
ros2 launch robotic_arm_controller controller.launch.py is_sim:=True

# Terminal 3 — task_server (MoveItPy)
ros2 launch robotic_arm_remote remote_interface.launch.py is_sim:=True

# Terminal 4 — mandar goals (CLI de Actions, visto en R06)
ros2 action list                                                          # confirmar que aparece /task_server
ros2 action send_goal /task_server robotic_arm_msgs/action/RoboticArmTask "{task_number: 0}"
```

Las 7 tareas (`task_number` 0 a 6) probadas y funcionando en Gazebo: pose zero, posición inicial, rotar+abrir gripper, agarrar objeto, trasladar a centro, rotar a posición B sosteniendo, soltar en posición B.

## Próximos pasos (queda para [R08])

- Ejecutar contra el brazo real — bloqueado por el desacople de calibración entre el "0" del modelo y el "0" físico de los servos (ver sección más arriba).
- Evaluar si conviene migrar más adelante a la arquitectura desacoplada (action client Python propio contra `move_action` de `move_group`, en vez de `MoveItPy`), aprovechando lo aprendido en [[project_r06_actions_progress]].

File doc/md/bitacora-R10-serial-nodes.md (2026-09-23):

# Bitácora [R10] — Nodos `simple_serial_transmitter` y `simple_serial_receiver` (Python)

_Inicio: 2026-09-23_

## Contexto

Implementar dos nodos ROS2 en Python que hagan de puente entre un topic y el puerto serie, basados en el ejemplo del curso Udemy "Robotics and ROS 2 - Learn by Doing: Manipulators":

```
/home/ezequiel/cursos/Robotics-and-ROS2-Manipulators/Robotics-and-ROS-2-Learn-by-Doing-Manipulators/Section9_Build/arduinobot_ws/src/arduinobot_firmware
```

Archivos de referencia:
- `arduinobot_firmware/simple_serial_transmitter.py`
- `arduinobot_firmware/simple_serial_receiver.py`

(El curso también tiene versiones C++ en `src/` y sketches `.ino` en `firmware/`; en esta tarea solo se hace la versión Python.)

## Cómo funcionan los nodos del curso

| Nodo | Entrada | Salida | Mecanismo |
|---|---|---|---|
| `simple_serial_transmitter` | topic `serial_transmitter` (`std_msgs/String`) | puerto serie | subscriber → `serial.write()` |
| `simple_serial_receiver` | puerto serie | topic `serial_receiver` (`std_msgs/String`) | timer (10 ms) → `serial.readline()` → publish |

Ambos leen los parámetros `port` (default `/dev/ttyUSB0`) y `baudrate` (default `115200`).

### ¿Por qué el receiver usa un timer y no un callback?

El executor de ROS2 solo despierta callbacks por entidades que conoce (subscriptions, timers, services). El puerto serie de `pyserial` no es una de ellas: ROS no se entera de que llegaron bytes. Por eso se hace **polling** con un timer.

Alternativa: un thread dedicado bloqueado en `readline()` que publica al recibir. Menor latencia, pero agrega manejo de concurrencia y cierre ordenado del thread. Para esta tarea alcanza con el timer.

### Problema: `readline()` bloquea el executor

El puerto se abre con `timeout=0.1` (100 ms) y el timer corre cada 10 ms. Si no llega nada, `readline()` se queda bloqueado hasta 100 ms esperando un `\n`, con el executor trabado dentro del callback. Resultado: el timer corre de hecho a ~10 Hz en vez de 100 Hz, y ningún otro callback del nodo puede ejecutarse mientras tanto.

### Bugs del `timerCallback` del curso

```python
data = self.arduino_.readline()
try:
    data.decode("utf-8")
except:
    return
msg.data = str(data)
self.pub_.publish(msg)
```

1. **Publica aunque no haya llegado nada:** con timeout, `readline()` devuelve `b''` y se publica igual → mensajes basura cada ~100 ms.
2. **`str(data)` no decodifica:** devuelve la representación del objeto `bytes`. Se publica el texto literal `b''` o `b'hola\n'`. El resultado de `decode()` se descarta; solo se usa como validación.
3. **`except:` pelado:** también atrapa `KeyboardInterrupt` y errores propios, escondiendo bugs.

Corrección acordada:
- Si `data` viene vacío → `return`.
- Guardar el resultado de `data.decode("utf-8")` en una variable dentro del `try` y publicar esa variable.
- Capturar `UnicodeDecodeError` específicamente.
- `.strip()` para sacar el `\n` / `\r\n` final.

## Decisión: paquete nuevo `robotic_arm_firmware`

Los nodos van en un paquete nuevo, separado de `robotic_arm_controller` / `robotic_arm_remote`, porque son la **capa de hardware**. Esa separación es la que permite más adelante cambiar la comunicación directa por la variante con ESP32 (ver `[E07]`) sin tocar el resto. También es el lugar natural para el plugin `ros2_control` de `[R09]` (C++).

Build type: **`ament_cmake`** (igual que el resto del workspace), para poder tener nodos Python y C++ en el mismo paquete.

```bash
cd robotic_arm_ws/src
ros2 pkg create --build-type ament_cmake robotic_arm_firmware
```

### Qué hace falta para nodos Python en un paquete `ament_cmake`

`CMakeLists.txt` (referencia: `robotic_arm_controller/CMakeLists.txt`):
- `find_package(ament_cmake_python REQUIRED)`
- `ament_python_install_package(${PROJECT_NAME})` — requiere la carpeta `robotic_arm_firmware/` con `__init__.py`.
- `install(PROGRAMS ... DESTINATION lib/${PROJECT_NAME})`

`package.xml`:
- `<buildtool_depend>ament_cmake_python</buildtool_depend>`
- `<exec_depend>` para `rclpy`, `std_msgs` y **`python3-serial`** (clave rosdep de `pyserial`; sin ella, en otra máquina el nodo falla con `ModuleNotFoundError: serial`).

### ¿Para qué sirve `__init__.py`?

Marca una carpeta como **paquete** de Python (una carpeta de módulos importable). Usos:

1. **Hacerla importable:** con `robotic_arm_firmware/__init__.py` presente, funciona `from robotic_arm_firmware import algo`.
2. **Código de inicialización:** lo que contenga se ejecuta una vez, la primera vez que se importa el paquete. Normalmente queda vacío.
3. **Definir la API pública:** por ejemplo, `from .serial_utils import open_port` dentro de `__init__.py` permite `from robotic_arm_firmware import open_port` sin conocer el archivo interno.

Matiz: desde Python 3.3 existen los *namespace packages* (carpetas sin `__init__.py` que igual se pueden importar), pero muchas herramientas de empaquetado lo exigen. `ament_python_install_package` es una de ellas: sin `__init__.py` el build falla. Por eso en ROS2 siempre se crea, aunque esté vacío.

## Troubleshooting: build roto después de actualizar ROS con apt

Al correr `colcon build` después de crear el paquete, falló **`robotic_arm_msgs`** (paquete ya existente, no el nuevo):

```
gmake[2]: *** No rule to make target '/opt/ros/jazzy/lib/libfastcdr.so.2.2.7',
needed by 'librobotic_arm_msgs__rosidl_typesupport_fastrtps_c.so'.  Stop.
```

`robotic_arm_firmware` y `robotic_arm_controller` figuraron como *aborted* solo porque colcon cortó al fallar otro paquete.

**Causa:** un `apt upgrade` actualizó Fast CDR de 2.2.7 a 2.2.8. En `/opt/ros/jazzy/lib/` quedó `libfastcdr.so.2.2.8` y la 2.2.7 fue eliminada, pero la configuración de CMake cacheada en `build/robotic_arm_msgs/` (`build.make`, `link.txt`) conservaba la ruta absoluta a la versión vieja.

**Solución:** borrar el build de ese paquete para forzar una reconfiguración de CMake (son artefactos regenerables):

```bash
cd robotic_arm_ws
rm -rf build/robotic_arm_msgs install/robotic_arm_msgs
colcon build
```

**Regla general:** después de actualizar paquetes de ROS con apt, si aparece un error de `No rule to make target '/opt/ros/...'` con una versión de librería que ya no existe, es caché de CMake desactualizado. Se arregla borrando `build/<paquete>` e `install/<paquete>` del paquete afectado (o todo `build/ install/ log/` si son varios).

## Implementación

### `CMakeLists.txt` y `package.xml`

- `install(PROGRAMS ...)` sin `RENAME`: los nodos se ejecutan con `.py` (`ros2 run robotic_arm_firmware simple_serial_receiver.py`). Decisión consciente.
- `package.xml` final: `buildtool_depend` `ament_cmake` + `ament_cmake_python`; `depend` `rclpy` + `std_msgs`; `exec_depend` `python3-serial`.
- Se descartaron `rclcpp`, `libserial-dev` y el chequeo `pkg_check_modules(libserial)`: son dependencias de **C++**, ningún archivo del paquete las usa. Vuelven cuando se haga el plugin de `[R09]`.

Qué instala cada función (verificado en `install/robotic_arm_firmware/`):
- `ament_python_install_package` → `lib/python3.12/site-packages/robotic_arm_firmware/` (módulo importable con `import`).
- `install(PROGRAMS)` → `lib/robotic_arm_firmware/` (ejecutables, donde busca `ros2 run`). Requiere el shebang `#!/usr/bin/env python3`.

### `pyserial`: tres nombres para la misma librería

| Dónde | Nombre |
|---|---|
| pip / PyPI | `pyserial` |
| Código | `import serial` |
| apt / rosdep (`package.xml`) | `python3-serial` |

Trampa: en PyPI existe otro paquete llamado `serial` (serialización) que pisa el módulo; nunca `pip install serial`.

### Receiver

```python
def timerCallback(self):
    if rclpy.ok() and self.serial_port.is_open:
        try:
            data = self.serial_port.readline().strip()
            if not data:
                return
            msg = String()
            msg.data = data.decode("utf-8")
            self.pub_.publish(msg)
        except UnicodeDecodeError as e:
            self.get_logger().warning(f"Invalid UTF-8 on serial: {e}")
```

Logging en rclpy: `self.get_logger().<nivel>(...)` con niveles `debug`, `info`, `warning`, `error`, `fatal`. Para evitar spam: `throttle_duration_sec=1.0`.

### Transmitter: framing con `\n`

El receiver (`readline()`) y el firmware cortan mensajes por `\n`, pero el transmitter original mandaba `msg.data` tal cual → el eco nunca salía. El `\n` lo agrega el **transmitter**: el framing es un detalle del enlace serie; quien publica en el topic no debería conocerlo.

```python
data_to_send = (msg.data + "\n").encode("utf-8")
self.serial_port.write(data_to_send)
```

Error evitado: `msg.data.encode("utf-8") + "\n"` → `TypeError: can't concat str to bytes`. Alternativa válida: `msg.data.encode("utf-8") + b"\n"`.

El `\n` es una convención del protocolo, no una obligación. Opciones de framing:
- **Delimitador de texto (`\n`)**: simple y legible; el delimitador no puede aparecer en los datos.
- **Marcadores STX/ETX (+ checksum)**: como en `[E05]`; permite resincronizar y detectar corrupción.
- **Largo en el encabezado**: como el protocolo de los servos (`[E04]`); necesario con payload binario arbitrario.

Para otro delimitador en Python: `read_until(expected=b'\x03')`. Regla: transmitter, receiver y firmware tienen que usar la misma.

## Prueba con Arduino Nano

### ¿Por qué no con el monitor serie?

Un puerto serie lo abre **un solo proceso**. Si el nodo abre `/dev/ttyUSB0`, el Serial Monitor / `idf.py monitor` no puede usarlo (y si se fuerza, se reparten los bytes). Los topics pasan a ser la ventana: `ros2 topic pub` = teclado, `ros2 topic echo` = pantalla.

### ¿Por qué Nano y no ESP32?

Se evaluó usar el `uart_echo` del ESP32 sobre UART0 (USB). Es viable y más realista, pero:
- los logs de ESP-IDF salen por UART0 y el receiver los publicaría como datos (hay que bajar el log level o mover la consola en `menuconfig`),
- los mensajes del bootloader del ROM no se pueden desactivar desde menuconfig,
- el auto-reset por DTR/RTS reinicia la placa al abrir el puerto,
- hay que reconfigurar el ejemplo (UART 0 en vez de UART2 17/16).

Se eligió el Nano: su `Serial` **es** el USB y no hay ruido de logs → prueba más limpia.

### Sketch de eco

`firmware/arduino-uart-echo/uart-echo/uart-echo.ino`: acumula caracteres hasta `\n`, devuelve la línea con `Serial.println()` (que manda `\r\n`, limpiado por `.strip()` en el receiver) y además prende/apaga el LED del pin 13 con `ON`/`OFF`. Baudrate **115200**, igual al default de los nodos.

### Procedimiento

```bash
# T1
ros2 run robotic_arm_firmware simple_serial_receiver.py
# T2
ros2 run robotic_arm_firmware simple_serial_transmitter.py
# T3
ros2 topic echo /serial_receiver
# T4 (--once publica un mensaje y termina)
ros2 topic pub --once /serial_transmitter std_msgs/msg/String "{data: 'ON'}"
ros2 topic pub --once /serial_transmitter std_msgs/msg/String "{data: 'OFF'}"
```

Notas:
- El Nano (chip FTDI FT232R) aparece como `/dev/ttyUSB0`, el default del parámetro `port`. Si no, `--ros-args -p port:=/dev/ttyXXX`.
- El Nano se resetea al abrirse el puerto (DTR): esperar ~2 s antes de publicar.
- Para subir un sketch hay que **frenar los nodos** primero: ocupan el mismo puerto que usa el IDE para programar. (Primer intento sin respuesta: el sketch nunca se había subido.)

### Resultado

```
❯ ros2 topic echo /serial_receiver
data: 'ON'
---
data: 'OFF'
---
```

Eco correcto de punta a punta y LED respondiendo a `ON`/`OFF`. Los datos llegan decodificados (`'ON'`, no `b'ON'`), lo que confirma el arreglo del bug de `str(data)`.

_Completada: 2026-09-23_

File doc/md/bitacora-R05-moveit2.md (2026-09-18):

# Bitácora — R05: Implementar MoveIt2 para planificación de movimiento del brazo

## Objetivo

Integrar MoveIt2 al workspace ROS2 (`robotic_arm_ws`) para poder planificar y ejecutar movimientos del brazo, en vez de comandar joints a mano. Referencia de curso: `arduinobot_ws` (Section6_Kinematics) en `/home/ezequiel/cursos/Robotics-and-ROS2-Manipulators/Robotics-and-ROS-2-Learn-by-Doing-Manipulators/`.

## Contexto

El usuario hace esta tarea en modo aprendizaje (mentor): escribe/ejecuta él, el asistente pregunta el porqué y corrige hasta que la explicación es correcta, sin escribir código de la tarea por él.

Punto de partida: workspace ya tiene `robotic_arm_description` (URDF/xacro, ver [R02](bitacora-R02-gazebo.md)) y `robotic_arm_controller`, pero ningún paquete de MoveIt2 todavía.

## Conceptos — comunicación ROS2 (tópicos, servicios, acciones)

Antes de tocar MoveIt2, se repasaron los tres mecanismos de comunicación de ROS2, arrancando de dos ejemplos del proyecto de referencia (`simple_service_server.py` / `simple_service_client.py`, patrón `AddTwoInts`).

| | Tópicos | Servicios | Acciones |
|---|---|---|---|
| Patrón | Pub/Sub (many-to-many) | Request/Response (1 a 1) | Goal/Feedback/Result (1 a 1) |
| Duración | Continuo, streaming | Instantáneo | Larga, con progreso |
| ¿Bloquea al cliente? | No aplica | Opcional (`call()` sync o `call_async()`) | No — siempre async por diseño |
| ¿Feedback intermedio? | N/A (es el feedback en sí) | No | Sí, mientras ejecuta |
| ¿Cancelable? | No aplica | No | Sí (`cancel_goal`) |
| Archivo de definición | `.msg` | `.srv` (Request / Response) | `.action` (Goal / Result / Feedback) |
| Ejemplo en MoveIt2 | `/joint_states` | `/compute_ik`, `/compute_fk` | ejecutar trayectoria (`FollowJointTrajectory`) |
| Cuándo usarlo | Datos que cambian constantemente, nadie "pide" nada puntual | Cálculo o consulta rápida, sin necesidad de progreso | Tarea que tarda y donde importa el progreso (o poder frenarla) |

**Por qué MoveIt2 no ejecuta trayectorias con un servicio**: un servicio solo puede devolver una única respuesta, al final. No hay forma estándar de reportar progreso durante el movimiento ni de cancelarlo a mitad de camino. Una acción sí: el servidor manda `Feedback` periódico mientras ejecuta y el cliente puede mandar `cancel_goal` en cualquier momento.

**Ciclo de vida de una acción**:
1. El cliente manda el `Goal`.
2. El servidor lo acepta/rechaza; mientras ejecuta, publica `Feedback` (progreso, posición actual, etc.).
3. Al terminar (éxito, error o cancelación), el servidor manda el `Result` una sola vez. El cliente nunca manda feedback ni result, solo `Goal` y opcionalmente `cancel_goal`.

**Por qué IK/FK sí son servicios (`/compute_ik`, `/compute_fk`)**: calcular la cinemática es instantáneo (no hay movimiento físico de por medio), así que no necesita feedback progresivo — encaja en el modelo request/response.

## Referencias

- Documentación oficial de MoveIt2: https://moveit.picknik.ai/main/index.html

## Comandos ejecutados

Siguiendo el video del curso (`arduinobot_moveit` como referencia), se creó el paquete `robotic_arm_moveit` con el mismo build-type que usa el curso:

```bash
ros2 pkg create --build-type ament_cmake robotic_arm_moveit
```

**Error detectado:** el comando se corrió parado en la raíz de `robotic_arm_ws`, no adentro de `src/` (mismo tipo de error que en [R02](bitacora-R02-gazebo.md), pero al revés — ahí `colcon build` se corrió desde `src/` en vez de la raíz). Resultado: `robotic_arm_moveit` quedó como carpeta hermana de `build/install/log/src`, en vez de paquete dentro de `src/`.

Se verificó que `colcon build` nunca llegó a correr después de crear el paquete mal ubicado (ni `build/` ni `install/` tenían rastro de `robotic_arm_moveit`, y el último log de build era anterior a la creación del paquete) — un intento posterior de correr `colcon build` se pegoteó con el comando anterior en la terminal (`...robotic_arm_moveitcolcon build`) y falló en el parser de `ros2` antes de invocar `colcon`. Conclusión: `build/`, `install/` y `log/` estaban intactos, no hacía falta borrarlos — alcanzaba con el fix mínimo.

**Fix aplicado:** se borró solo la carpeta `robotic_arm_moveit` mal ubicada, se recreó el paquete parado dentro de `src/`, y se corrió `colcon build` desde la raíz del workspace. Resultado verificado: `robotic_arm_moveit` aparece correctamente en `src/`, `build/` e `install/`, junto a `robotic_arm_controller` y `robotic_arm_description`.

## SRDF (`config/robotic_arm.srdf`)

**Primer borrador con error grave:** el primer guardado del archivo resultó ser el SRDF de `arduinobot` casi sin adaptar (se ve que no se había guardado el archivo real cuando se pidió revisión). Evidencia encontrada al comparar contra el URDF real:
- `<robot name="arduinobot">` en vez de `robotic_arm`.
- Grupo `gripper` con joints `joint_4`/`joint_5`, que no existen en el robot (el joint real es `gripper`, único).
- Los `group_state name="home"` referenciaban `joint_1`/`joint_2`/`joint_3`/`joint_4`, inexistentes.
- Todo el bloque `disable_collisions` apuntaba a links de `arduinobot` (`base_plate`, `forward_drive_arm`, `claw_support`, `gripper_left`, `gripper_right`, `horizontal_arm`), ninguno presente en este robot.

Se corrigió (tras guardar el archivo real): `robot name="robotic_arm"` ✓, grupo `gripper` con el joint real `gripper` ✓, `group_state` con los joints reales de cada grupo ✓.

**Grupos definidos:**
- `arm`: `virtual_joint`, `shoulder_pan`, `shoulder_lift`, `elbow_flex`, `wrist_flex`, `wrist_roll`.
- `gripper`: `gripper`.

**Colisiones (`disable_collisions`)** — cadena cinemática real (de `parent`/`child` en el xacro): `base_link → shoulder_link → upper_arm_link → lower_arm_link → wrist_link → gripper_link → {moving_jaw_so101_v1_link, gripper_frame_link}`. `gripper_frame_link` no tiene `<collision>` en el URDF, así que nunca participa en chequeos.

- 6 pares `Adjacent` (padre-hijo directo): `base_link`–`shoulder_link`, `shoulder_link`–`upper_arm_link`, `upper_arm_link`–`lower_arm_link`, `lower_arm_link`–`wrist_link`, `wrist_link`–`gripper_link`, `gripper_link`–`moving_jaw_so101_v1_link`.
- 9 pares `Never` (geométricamente no llegan a tocarse): los 5 que salen de `base_link` contra links lejanos, más `upper_arm_link`–`wrist_link`, `lower_arm_link`–`gripper_link`, `lower_arm_link`–`moving_jaw_so101_v1_link`, `wrist_link`–`moving_jaw_so101_v1_link`.
- 6 pares dejados **sin marcar a propósito** (quedan habilitados/chequeados): `shoulder_link` contra `lower_arm_link`/`wrist_link`/`gripper_link`/`moving_jaw_so101_v1_link`, y `upper_arm_link` contra `gripper_link`/`moving_jaw_so101_v1_link`. Validado físicamente en el brazo real (impreso en PLA, armado) que sí colisionan en algún punto del recorrido combinado de varios joints — no es un caso de un solo joint pasándose de rango (como el de abajo), sino de una combinación de joints plegados. No hay un `<limit>` único que lo prevenga sin sacrificar rango útil, así que se deja que el planner de MoveIt2 los descarte en tiempo real.

**Discusión — `disable_collisions` vs. límites de joint:** se identificó que la matriz de colisiones (ACM) es estática y binaria por par de links: no varía según el ángulo del joint. Para el caso `base_link`–`shoulder_link`, que además de tocarse en el pivote (zona `Adjacent` normal) puede chocar de verdad si `shoulder_pan` gira a un ángulo peligroso, se decidió **ajustar el `<limit>` del joint** para excluir ese ángulo del rango planificable, en vez de dejar el par habilitado — así `Adjacent` queda seguro porque el ángulo peligroso nunca es alcanzable. Pendiente: medir y ajustar el `upper`/`lower` real de `shoulder_pan` en el xacro.

## Archivos de configuración adicionales

Agregados en `config/`: `initial_positions.yaml`, `joint_limits.yaml`, `kinematics.yaml`, `moveit_controllers.yaml`, `pilz_cartesian_limits.yaml`.

**Typos de nombre de archivo corregidos:** `joints_limits.yaml` → `joint_limits.yaml` (singular, nombre que MoveIt2 busca por convención), `pliz_cartesian_limits.yaml` → `pilz_cartesian_limits.yaml` (planner Pilz).

**`joint_limits.yaml` — velocidades muy por encima del hardware real.** Config original: `max_velocity: 10.0` (rad/s) para todos los joints. Cálculo de conversión steps/s → rad/s: `rad/s = steps/s × (2π / 4096)` (4096 steps = 1 vuelta del servo STS3215).

Se detectó y corrigió un error propio: inicialmente se citó "techo de hardware ~50 RPM (~5.22 rad/s)" tomado de un comentario en `STServo_Python/servo_control_ui.py` que decía "(STS3215 datasheet)" sin haber verificado la fuente real — el repo no tiene el datasheet en PDF, solo un mapa de registros XLS. Se buscó el dato real en la wiki oficial de Waveshare (mismo fabricante que el Bus Servo Adapter usado en el proyecto, ver [E03](bitacora-E03-adaptador-logico.md)/[E04](bitacora-E04-protocolo-driver.md)):

> No-load Speed: 0.222 sec/60° (**45 RPM @ 12V**) — https://www.waveshare.com/wiki/ST3215_Servo

El voltaje real de la fuente del proyecto es 12.3V (medido con multímetro, ver `assembly.md`), así que el dato de 12V aplica directamente. Corroborado por medición independiente de terceros (~46 RPM máx., ~45.6 RPM promedio al 100%) en https://servodatabase.com/servo/feetech/sts3215.

Techo real: `45 RPM × 2π/60 ≈ 4.71 rad/s`. Comparación:
- `max_velocity: 10.0` configurado ≈ **2.1×** el techo real del servo — MoveIt2 podría planear velocidades que el hardware no puede alcanzar (error de seguimiento de trayectoria, o estrés mecánico en piezas PLA dado el backlash ya investigado en [R04](BACKLOG.md)).
- Contra el perfil "gentle" ya validado en el brazo real (`MOVE_SPEED = 300` steps/s ≈ 0.46 rad/s): ≈ **21.7×** más rápido.
- `max_acceleration: 5.0` (rad/s²) configurado queda por debajo del techo real (`ACC_MAX=50` unidades × 100 steps/s² × 2π/4096 ≈ 7.67 rad/s²) — más discutible, no tan urgente como la velocidad.

**Valores finales elegidos:** margen del 10% por debajo del techo real del servo, en vez de usar el techo absoluto o el perfil gentle directamente (compensa con `default_velocity_scaling_factor: 0.1`/`default_acceleration_scaling_factor: 0.1`, que ya están en el archivo, para la velocidad efectiva de uso normal).

- `max_velocity`: `45 RPM × 0.9 = 40.5 RPM` → `40.5 × (2π/60) ≈ 4.24 rad/s`.
- `max_acceleration`: techo real `ACC_MAX = 50` unidades × `100 steps/s²`/unidad `= 5000 steps/s²` → `× (2π/4096) ≈ 7.67 rad/s²`. Con el mismo margen del 10%: `7.67 × 0.9 ≈ 6.90 rad/s²`.

Ambos valores aplicados a los 6 joints (`shoulder_pan`, `shoulder_lift`, `elbow_flex`, `wrist_flex`, `wrist_roll`, `gripper`) en `joint_limits.yaml`. Se evaluó usar YAML anchors/aliases (`&`/`*`) para no repetir el bloque 6 veces, pero se decidió mantenerlo explícito por ahora, para entender bien cada bloque mientras se aprende.

**Resto de archivos, revisados sin hallazgos:** `kinematics.yaml` (KDL, `position_only_ik: true` — correcto, el brazo tiene 5 joints revolutos = 5 DOF, no alcanza para pose completa de 6 DOF). `moveit_controllers.yaml` (nombres de controller `arm_controller`/`gripper_controller` coinciden con los reales, usados también en `slider_control.py`). `initial_positions.yaml` (joints con nombres reales, todos en 0).

**`pilz_cartesian_limits.yaml` — dejado con los defaults del curso, sin adaptar.** A diferencia de `joint_limits.yaml`, acá no hay una conversión limpia de una sola variable (la velocidad cartesiana en la punta depende de la pose y de qué joints se mueven a la vez, no de un solo servo). Estimación gruesa con los offsets reales del xacro: brazo de palanca desde `shoulder_lift` hasta la punta ≈ suma de `upper_arm_link` (0.116 m) + `lower_arm_link` (0.135 m) + `wrist_link` (0.064 m) + `gripper_link` (0.036 m) ≈ **0.35 m**. A `max_velocity` (4.24 rad/s), el peor caso en la punta sería `4.24 × 0.35 ≈ 1.48 m/s` — por encima del `max_trans_vel: 1.0` configurado, así que el límite cartesiano actual no es un valor inofensivo/permisivo, actúa como tope real. Se decidió dejarlo así por ahora: no bloqueante (no hay `launch/` todavía que use el planner Pilz), y la validación precisa requeriría simulación, no cálculo a mano.

## DDS y cambio a Cyclone DDS

El curso indica que la documentación de MoveIt2 reporta problemas con la implementación default de DDS de ROS2, y pide cambiar a Cyclone DDS.

**Qué es DDS:** protocolo de middleware (estándar OMG) que ROS2 usa por debajo para toda la comunicación (tópicos, servicios, acciones — ver tabla más arriba). A diferencia de ROS1 (que necesitaba un `roscore` central), ROS2 no tiene nodo maestro: cada nodo se descubre con los demás vía DDS (multicast UDP), de forma descentralizada. ROS2 no implementa DDS desde cero — delega en una implementación externa a través de la interfaz **RMW** (ROS MiddleWare), intercambiable con la variable de entorno `RMW_IMPLEMENTATION`. Implementaciones disponibles: Fast DDS (eProsima, default histórico), Cyclone DDS (Eclipse), Connext DDS (RTI, comercial).

**Instalación:**
```bash
sudo apt install ros-jazzy-rmw-cyclonedds-cpp
```

**Activación**, agregada al final de `~/.zshrc` (no `.bashrc`, porque el shell del usuario es zsh — mismo criterio que el alias `ros_jazzy`):
```bash
export RMW_IMPLEMENTATION=rmw_cyclonedds_cpp
```

Es solo una variable de entorno — no depende de haber corrido `ros_jazzy` antes o después; se exporta automáticamente al abrir cualquier terminal nueva (por estar en `.zshrc`), y recién se usa cuando un programa ROS2 arranca y la lee para decidir qué librería de RMW cargar.

**Validación:** `echo $RMW_IMPLEMENTATION` en una terminal nueva — debe devolver `rmw_cyclonedds_cpp`.

## Launch de MoveIt2 (`launch/moveit.launch.py`) y prueba end-to-end

Creado `launch/moveit.launch.py`, usando `MoveItConfigsBuilder("robotic_arm", package_name="robotic_arm_moveit")` para armar la config (URDF, SRDF, `moveit_controllers.yaml`), y dos nodos: `move_group` (paquete `moveit_ros_move_group`) y `rviz2` con los parámetros de MoveIt cargados.

**Hallazgos en `package.xml`:**
- Typo: `<exec_depend>moveit_config_utils</exec_depend>` — falta la "s", el paquete real es `moveit_configs_utils` (coincide con el import real en `moveit.launch.py` línea 3, que sí está bien escrito).
- Falta declarar `moveit_ros_move_group` como `exec_depend` (es el paquete que provee el ejecutable `move_group` que el launch arranca). El proyecto de referencia (`arduinobot_moveit`) sí lo declara.
- Ninguno de los dos bloqueó el build porque `colcon build` no valida existencia de paquetes en `exec_depend` (eso lo haría `rosdep`) — pendiente de corregir para que el `package.xml` documente correctamente las dependencias reales.

**`config/moveit.rviz` no existe:** el launch le pide a RViz cargar `config/moveit.rviz` (línea 49), que no está creado. No bloqueó nada — RViz abrió con layout vacío, y se configuró a mano (Fixed Frame `world` + display "MotionPlanning").

**Prueba end-to-end, exitosa:**

Secuencia de terminales:
```bash
# Terminal 1
colcon build
. install/setup.zsh
ros2 launch robotic_arm_description gazebo.launch.py

# Terminal 2
ros2 launch robotic_arm_controller controller.launch.py
ros2 launch robotic_arm_moveit moveit.launch.py
```

En RViz, dentro del display "MotionPlanning": en la pestaña **Context** se verificó que el planner sea OMPL (`ros-jazzy-moveit-planners-ompl`, ya estaba instalado); en la pestaña **Planning** se marcó **"Approx IK Solutions"** (relevante porque el robot tiene `position_only_ik: true` — 5 DOF, no siempre hay solución exacta de IK). Con el planning group `arm` seleccionado, se arrastró la esfera interactiva (goal) desde la pose actual (modelo rojo) y se presionó **Plan & Execute**.

**Resultado:** el brazo llegó al goal correctamente — tanto en RViz como en el modelo simulado de **Gazebo**, confirmando el flujo completo: MoveIt2 planifica → manda la trayectoria por la acción `FollowJointTrajectory` → `arm_controller` de `ros2_control` la ejecuta sobre el modelo simulado. Cierra el objetivo central de R05.

**Prueba del grupo `gripper`:** mismo procedimiento, con una diferencia — al ser un solo joint revoluto (no una cadena que necesite IK), no aparece el marcador interactivo de pose. El goal se generó con la opción **"Random valid"** del Query Goal State en el panel de MotionPlanning. Confirmado OMPL en la pestaña Context. Plan & Execute: el gripper llegó al goal correctamente.

Con `arm` y `gripper` planificando y ejecutando bien en simulación, el objetivo central de R05 queda cumplido.

**Pendiente:** corregir el `package.xml` (typo + dependencia faltante), decidir si crear `moveit.rviz`.

## Medición física del límite de `shoulder_pan`

Para resolver el pendiente de la sección SRDF (¿el `<limit>` heredado del URDF original de SO-ARM100 cubre el choque real de este ensamblaje?), se agregó una herramienta de medición a `STServo_Python/servo_control_ui.py` (fuera del modo mentor de R05 — tooling de apoyo, escrita directamente).

**Herramienta agregada:** sección "Medicion de limites (URDF)" en la UI — combobox para elegir servo, lectura en vivo de counts + radianes relativos al cero calibrado (`ZERO_COUNTS = 2048`, mismo valor que `DEFAULT_TARGET` en `calibrate-arm.py`; el `homing_offset` ya está aplicado en la EEPROM del servo, así que el counts crudo ya viene relativo a ese cero), botones "Marcar minimo"/"Marcar maximo" que capturan la posición actual, y una línea `<limit lower=".." upper=".." .../>` calculada automáticamente (ordena lower/upper por si se marcan al revés). Todo se loggea por stdout para poder pegar el log.

**Medición real de `shoulder_pan`** (torque off, movido a mano hasta el punto de contacto):
```
[MEDICION] shoulder_pan (id=1) -> <limit lower="-2.02332" upper="2.09388" .../>
```
(-115.93° / 119.97°)

**Comparación contra el límite actual del xacro** (`lower="-1.91986" upper="1.91986"`, ±110.0°, heredado del URDF original de SO-ARM100 sin verificar hasta ahora):
- Lado negativo: choque real a -115.93°, límite actual en -110° → margen de 5.9°.
- Lado positivo: choque real a 119.97°, límite actual en 110° → margen de 9.97°.

**Conclusión:** el límite heredado, pese a no haber sido derivado de este ensamblaje físico, sí cubre el choque real con margen en ambos lados — **no hace falta modificar el `<limit>` del xacro**. Confirmado con medición real, no con una suposición. (Asunción usada en el cálculo: el signo de los counts crudos coincide con el signo del eje del joint sin inversión, válido porque `drive_mode: 0` en `calibration.json` para este servo.)

Con esto, el pendiente de `shoulder_pan` marcado en la sección SRDF queda resuelto: el `disable_collisions reason="Adjacent"` de `base_link`–`shoulder_link` es seguro tal como está.

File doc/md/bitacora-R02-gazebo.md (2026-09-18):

# Bitácora — R02: Levantar el URDF de SO101 en Gazebo (ROS2)

## Objetivo

Armar el paquete/workspace ROS2 necesario para simular el brazo SO101 en Gazebo, partiendo del URDF vendorizado en `ros2/urdf/so101/` (ver [R01](bitacora-R01-urdf.md)).

## Contexto

El usuario está haciendo esta tarea por su cuenta (modo aprendizaje); esta bitácora registra los pasos y comandos ROS2 que va ejecutando, a medida que los va pasando.

## Configuración del entorno

- Guía seguida para configurar ROS2 en la computadora: [`Configure the Development Environment in Ubuntu 24.04.pdf`](../datasheets/Configure+the+Development+Environment+in+Ubuntu+24.04.pdf)

## Activación del entorno ROS2

Para activar el entorno de ROS2 en la terminal se usa el alias `ros_jazzy`, definido en `~/.zshrc`:

```bash
alias ros_jazzy="source /opt/ros/jazzy/setup.zsh"
```

Este alias ejecuta el script `setup.zsh` que instala ROS2 Jazzy en `/opt/ros/jazzy/`. Ese script no "arranca" nada, sino que exporta en la sesión actual de la terminal las variables de entorno que las herramientas de ROS2 necesitan para funcionar: `ROS_DISTRO`, `AMENT_PREFIX_PATH` (dónde buscar paquetes instalados), `PYTHONPATH` (para poder importar los módulos Python de ROS2/`rclpy`) y agrega los binarios (`ros2`, `colcon`, etc.) al `PATH`. Por eso hay que correrlo en cada terminal nueva antes de usar comandos `ros2` o `colcon` — es exclusivo de esa sesión de shell, no queda activado a nivel sistema.

## Comandos ejecutados

```bash
mkdir -p robotic_arm_ws/src
```
Creación del workspace ROS2 (`robotic_arm_ws`), con la carpeta `src/` donde van los paquetes.

```bash
cd robotic_arm_ws/src
ros_jazzy
colcon build
```
Resultado: `Summary: 0 packages finished [0.44s]`.

**Error detectado:** `colcon build` se corrió parado adentro de `src/`, no en la raíz del workspace. Consecuencia: `build/`, `install/` y `log/` se generaron dentro de `src/` en vez de al lado (rompe la estructura estándar de un workspace ROS2, que es `<ws>/{src,build,install,log}`). Se corrigió borrando esos tres directorios (nada trackeado en git, sin pérdida) y volviendo a correr `colcon build` desde `robotic_arm_ws/` (un nivel arriba de `src/`).

```bash
cd ..
colcon build
```
Resultado: `Summary: 0 packages finished [0.35s]`, ahora con `build install log src` correctamente a la misma altura. Sigue en 0 porque todavía no hay ningún paquete creado dentro de `src/` — eso es lo que sigue.

```bash
cd src
ros2 pkg create --build-type ament_cmake robotic_arm_description
```
Creación del paquete `robotic_arm_description` (build type `ament_cmake`), convención estándar en ROS2 para paquetes que solo contienen URDF/meshes/launch (sin nodos). Emite un warning de licencia (`TODO: License declaration` no es una licencia válida) — cosmético, no bloquea el build.

```bash
cd ..
colcon build
```
Resultado: `Summary: 1 package finished [2.52s]` — compila `robotic_arm_description` correctamente, parado en la raíz del workspace.

```bash
cd robotic_arm_description
mkdir urdf
touch urdf/robotic_arm.urdf.xacro
mkdir meshes
```
Estructura del paquete `robotic_arm_description`: carpeta `urdf/` con un archivo placeholder `robotic_arm.urdf.xacro` (vacío, a completar) y carpeta `meshes/` para las mallas STL.

## Construcción de `robotic_arm.urdf.xacro`

Traducción del URDF plano (`ros2/urdf/so101/so101_new_calib.urdf`, de R01) al xacro del paquete, siguiendo el formato del proyecto de referencia del curso Udemy (ver [[repo-de-referencia-del-curso-udemy-para-r02]]).

- **`base_link`** (el primero, hecho paso a paso para aprender el patrón): copiado el inertial, las 4 partes visual/collision y sus orígenes desde el URDF original. Errores encontrados y corregidos en el camino:
  - `scale="0.01 0.01 0.01"` de más en los `<mesh>` (copiado sin pensar del proyecto de referencia — ver detalle técnico abajo).
  - Un `<mesh>` sin auto-cerrar (`<mesh .../>` faltaba la `/`) que rompía el parseo XML — detectado corriendo `xacro archivo.urdf.xacro` (exit code y error de línea exacta).
  - Faltaban las definiciones `<material name="...">` con el color (`3d_printed`, `sts3215`) — solo estaban referenciadas por nombre, nunca definidas.
- **Los 6 links restantes** (`shoulder_link`, `upper_arm_link`, `lower_arm_link`, `wrist_link`, `gripper_link`, `gripper_frame_link`, `moving_jaw_so101_v1_link`) los completé yo (a pedido del usuario, para ganar velocidad una vez entendido el patrón del primero), mismo criterio: rutas `package://robotic_arm_description/meshes/...`, sin `scale`, materiales referenciados.
- **Joints**: se decidió (razonamiento del usuario, correcto) usar propiedades xacro `${effort}` y `${velocity}` (valor `10`, idéntico en los 6 joints revolute del URDF original) pero **hardcodear** los límites `lower`/`upper` de cada joint, porque son datos de calibración real específicos de cada motor, no un valor genérico. El primer joint (`shoulder_pan`, base→shoulder) se armó paso a paso; los 5 restantes (`shoulder_lift`, `elbow_flex`, `wrist_flex`, `wrist_roll`, `gripper`) más el `gripper_frame_joint` (fijo) y un `virtual_joint` nuevo (`world`→`base_link`, necesario para tener una única raíz) los completé yo.
- **No se portaron los bloques `<transmission>`** del URDF original: son sintaxis vieja de `ros_control` (ROS1), que `ros2_control` (lo que se va a usar en Gazebo) no lee. Además todos tenían `mechanicalReduction="1"` (sin reducción real que modelar). Cuando se adapte el URDF para Gazebo va a hacer falta un bloque `<ros2_control>` en su lugar, no esto.
- **Verificación:** cada cambio se validó corriendo `xacro robotic_arm.urdf.xacro` (chequea que el XML resultante sea válido) y, tras completar todos los joints, `check_urdf` sobre el resultado — confirma un único root (`world`) y el árbol cinemático completo: `world → base_link → shoulder_link → upper_arm_link → lower_arm_link → wrist_link → gripper_link → {moving_jaw_so101_v1_link, gripper_frame_link}`.

## Decisiones y hallazgos técnicos

- **No usar `scale="0.01 0.01 0.01"` en los `<mesh>` del xacro.** Ese factor viene copiado del proyecto de referencia del curso (`arduinobot`), pero ahí corrige una malla modelada en otra unidad. Las mallas de SO101 (exportadas con `onshape-to-robot`) ya vienen en metros: verificado midiendo el bounding box de `base_motor_holder_so101_v1.stl` (~-0.02 a 0.07 en cada eje, consistente con una pieza de 5-9cm). Aplicar ese scale las achicaría 100x.
- **`scale` no afecta el rendimiento** (no cambia la cantidad de triángulos, solo el tamaño geométrico). El total real de la malla del brazo es **322.564 triángulos** (13 STL, el más pesado `wrist_roll_pitch_so101_v2.stl` con ~54.000). El riesgo real de performance en Gazebo es que el URDF reusa la misma malla de alto detalle para `<visual>` y `<collision>` — si hay lag/inestabilidad de física más adelante, la solución es simplificar la geometría de colisión (cajas/cilindros o convex hull), no tocar el scale.

```bash
cd robotic_arm_ws/src/robotic_arm_description
mkdir urdf meshes
# ... escritura de robotic_arm.urdf.xacro y CMakeLists.txt (ver arriba) ...
colcon build
```
**Error repetido:** de nuevo se corrió `colcon build` parado adentro del paquete (`robotic_arm_ws/src/robotic_arm_description/`) en vez de la raíz del workspace — generó `build/`, `install/`, `log/` mezclados con el código fuente del paquete. Se corrigió borrando esos tres directorios (nada trackeado, sin pérdida) y volviendo a correr `colcon build` parado en `robotic_arm_ws/`.

```bash
cd robotic_arm_ws
colcon build
```
Resultado: `Summary: 1 package finished [1.25s]` — correcto, parado en la raíz del workspace. Con el `install(DIRECTORY meshes urdf ...)` agregado al `CMakeLists.txt`, esta vez `colcon build` también copia las mallas y el xacro a `install/share/robotic_arm_description/`.

```bash
sudo apt install ros-jazzy-urdf-tutorial
```
Instalación del paquete `urdf_tutorial` (trae `display.launch.py`: levanta `robot_state_publisher` + `joint_state_publisher_gui` + RViz para visualizar y mover el URDF interactivamente). Paso previo a Gazebo, para validar visualmente el xacro armado.

```bash
ros2 launch urdf_tutorial display.launch.py model:=/home/ezequiel/proyecto-final/BrazoRobotico/robotic_arm_ws/src/robotic_arm_description/urdf/robotic_arm.urdf.xacro
```
Primer chequeo visual del xacro completo en RViz (`robot_state_publisher` + `joint_state_publisher_gui`). Resultado: **el brazo se ve completo y correcto**, todas las piezas presentes, sin errores de mallas faltantes ni de parseo. Capturas de pantalla tomadas con la herramienta de GNOME (`PrtScn`/`Shift+PrtScn`).

Configuración de RViz guardada en `robotic_arm_ws/src/robotic_arm_description/rviz/display.rviz` (carpeta `rviz/` nueva dentro del paquete, convención estándar de ROS2 para reutilizar la vista desde un launch file más adelante).

### Launch file propio para RViz

Creado `robotic_arm_ws/src/robotic_arm_description/launch/display.launch.py` (basado en el patrón del proyecto de referencia): declara el argumento `model` (default: xacro instalado del paquete), corre `xacro` sobre él vía `Command(...)` para publicar `robot_description`, y levanta `robot_state_publisher` + `joint_state_publisher_gui` + `rviz2` (con `-d` apuntando a `rviz/display.rviz`). Se agregó `install(DIRECTORY meshes urdf launch rviz ...)` al `CMakeLists.txt` y los `exec_depend` correspondientes (`robot_state_publisher`, `urdf`, `joint_state_publisher_gui`, `rviz2`, `xacro`, `ros2launch`) al `package.xml`.

**Bug encontrado y corregido (dos idas y vueltas):** al renombrar la variable `arduinobot_description_dir` → `robotic_arm_description_dir` (nombre pegado del proyecto de referencia), quedó una referencia sin actualizar en la línea del nodo de RViz (`arguments=["-d", os.path.join(arduinobot_description_dir, ...)]`) — hubiera tirado `NameError` al ejecutar `generate_launch_description()`. Detectado leyendo el archivo línea por línea (un primer intento de verificación con `ros2 launch ... --show-args` dio falso negativo por correr contra la copia vieja en `install/`, no contra el `src/` editado). Corregido y confirmado con:

```bash
colcon build
ros2 launch robotic_arm_description display.launch.py
```
Resultado: brazo visible en RViz, correcto.

### Launch file para Gazebo

Creado `robotic_arm_ws/src/robotic_arm_description/launch/gazebo.launch.py`: `robot_state_publisher` (con `use_sim_time: True`), include del launch de `ros_gz_sim` (`gz_sim.launch.py`, Gazebo Harmonic/Sim — no Gazebo clásico) con mundo vacío, `SetEnvironmentVariable` de `GZ_SIM_RESOURCE_PATH` (padre del share dir, para que Gazebo resuelva las mallas `package://`), spawn del robot vía `ros_gz_sim create` leyendo el tópico `robot_description`, y bridge de `/clock` (`ros_gz_bridge`). Agregados `ros_gz_sim`/`ros_gz_bridge` como `exec_depend` en `package.xml` (ya instalados en el sistema: `ros-jazzy-ros-gz-sim`, `ros-jazzy-ros-gz-bridge`, etc.). Esta vez sin el bug de variable a medio renombrar de la vez pasada — consistente en todo el archivo. Se sacó la variable `ros_distro` sin uso (código muerto).

```bash
colcon build
ros2 launch robotic_arm_description gazebo.launch.py
```
Resultado: **el brazo se spawnea y se ve bien en Gazebo** (mundo vacío, mallas correctas, sin errores).

## `ros2_control` + control de joints en Gazebo

Concepto: `ros2_control` abstrae el hardware (real o simulado) detrás de una interfaz uniforme — un `controller_manager` corre controladores que comandan/leen joints a través de `command_interface`/`state_interface`, sin saber si atrás hay un motor real o Gazebo. En Gazebo, esa "hardware" es el plugin `gz_ros2_control` (Gazebo Sim/Harmonic — no el `gazebo_ros2_control` de Gazebo clásico).

Estructura elegida, siguiendo el patrón del proyecto de referencia (separar en archivos xacro incluidos desde `robotic_arm.urdf.xacro` en vez de todo en un solo archivo):
- `robotic_arm_gazebo.xacro`: tag `<gazebo>` con el `<plugin>` `gz_ros2_control::GazeboSimROS2ControlPlugin`, apuntando a los parámetros del controller_manager.
- `robotic_arm_ros2_control.xacro`: tag `<ros2_control>` con `<hardware><plugin>gz_ros2_control/GazeboSimSystem</plugin></hardware>` y, por joint, `<command_interface>`/`<state_interface>`.
- Paquete nuevo **`robotic_arm_controller`** (mirando al `arduinobot_controller` de referencia): `config/robotic_arm_controllers.yaml` con la config del `controller_manager`.

**Errores encontrados en el camino:**
- Paquete `robotic_arm_controller` creado por error **fuera de `src/`** (directo en `robotic_arm_ws/`) — corregido moviéndolo a `robotic_arm_ws/src/robotic_arm_controller`.
- Nombre de archivo `robotic_arm_ros2_controll.xacro` (doble `l`) no coincidía con el `filename` del `xacro:include` (`robotic_arm_ros2_control.xacro`, una sola `l`) — hubiera fallado al procesar. Corregido renombrando el archivo.
- Como el `include` usa `$(find robotic_arm_description)/...`, xacro necesita el paquete resuelto vía `ament_index` — hace falta tener el workspace *instalado* (`colcon build` + sourcear `install/setup.zsh`), no alcanza con tener el archivo en `src/`.

**`robotic_arm_controllers.yaml`** (completado): `joint_state_broadcaster` (publica `/joint_states`), `arm_controller` (`JointTrajectoryController`, los 5 joints del brazo: `shoulder_pan`, `shoulder_lift`, `elbow_flex`, `wrist_flex`, `wrist_roll`) y `gripper_controller` (`JointTrajectoryController`, joint `gripper`).

**Decisión: `JointTrajectoryController` para el gripper, no `ForwardCommandController`.** El curso de referencia deja comentada la opción `ForwardCommandController` (más simple: aplica un valor directo, sin interpolar, sin action interface) y usa `JointTrajectoryController` para el gripper también — misma interfaz (action `FollowJointTrajectory` con feedback) para brazo y gripper. Ventaja: uniformidad si más adelante se integra MoveIt2 o se necesita esperar/coordinar el cierre del gripper con el resto del movimiento. `ForwardCommandController` hubiera sido más liviano para un gripper simple abrir/cerrar, pero se prioriza la interfaz uniforme.

**Pendiente:** agregar `install(DIRECTORY config DESTINATION share/${PROJECT_NAME})` al `CMakeLists.txt` de `robotic_arm_controller` (todavía no lo tiene) para que `$(find robotic_arm_controller)/config/robotic_arm_controllers.yaml` resuelva tras el build.

**Bug del `<xacro>` suelto:** apareció en los dos archivos nuevos (resto de sacar el `xacro:if`/`xacro:unless` del `is_ignition`). Corregido en `robotic_arm_gazebo.xacro` restaurando el patrón completo `xacro:if value="$(arg is_ignition)"` / `xacro:unless` (con `<xacro:arg name="is_ignition" default="false"/>` agregado al xacro principal — por defecto usa `gz_ros2_control`, la rama que corresponde a Jazzy) y, con el mismo criterio, en `robotic_arm_ros2_control.xacro` para el bloque `<hardware>`.

**Joints de `robotic_arm_ros2_control.xacro` completados** (a pedido del usuario, patrón ya entendido): los 6 joints revolute (`shoulder_pan`, `shoulder_lift`, `elbow_flex`, `wrist_flex`, `wrist_roll`, `gripper`), cada uno con `<command_interface name="position">` (min/max = límites reales de calibración, los mismos del URDF principal) y `<state_interface name="position"/>`. Se sacó la propiedad `PI` que había quedado sin usar. Verificado con `colcon build` + `xacro` (`exit: 0`, el `<gazebo>` y el `<ros2_control>` completo aparecen en el URDF final) + `check_urdf` (árbol cinemático intacto).

### Primer arranque con `ros2_control` completo

```bash
colcon build
ros2 launch robotic_arm_description gazebo.launch.py
```
Log revisado línea por línea. **Éxito:** `gz_ros_control` carga `controller_manager`, se suscribe a `/robot_description`, registra los 6 joints (`shoulder_pan`, `shoulder_lift`, `elbow_flex`, `wrist_flex`, `wrist_roll`, `gripper`) con `State: position` / `Command: position` (coincide con `robotic_arm_ros2_control.xacro`), inicializa y **activa** el hardware `RobotSystem` sin errores. Warnings esperados/benignos: joint fijo `virtual_joint` se salta (correcto, no es actuable), warning de "Executor not available"/"statistics" (normales en este plugin), warning de `update_rate` 10Hz vs paso de física 1000Hz (esperado, el control corre más lento que la física a propósito).

**Hallazgo real (no de `ros2_control`, del motor de física `dartsim`):** en el log aparece repetido para *todos* los links: `Mesh construction from an SDF has not been implemented yet for dartsim` + `The geometry element of collision [<link>_collision] couldn't be created`. `dartsim` no puede construir la geometría de `<collision>` directo desde malla STL — **el brazo ahora mismo no tiene colisión física en ningún link** (se ve bien porque el `<visual>` sí renderiza, pero no va a interactuar físicamente con nada). Esto confirma/adelanta el pendiente "Futuro" ya anotado (simplificar `<collision>` a formas primitivas) — pasa de ser hipotético a ser un problema real y actual.

**Chequeo cruzado con el proyecto de referencia:** se corrió `ros2 launch arduinobot_description gazebo.launch.py` sobre el `arduinobot_ws` del curso (Section5_Control) para confirmar si el problema de colisión con dartsim era general o específico de nuestro URDF. Mismo resultado exacto: `Mesh construction... has not been implemented yet for dartsim` + `The geometry element of collision [...] couldn't be created` para todos sus links. **Confirma que es una limitación conocida de `dartsim`, no un error de nuestro proyecto.** Bonus: el log de referencia también muestra que dartsim no soporta joints "mimic" (`[Err] ... physics engine does not support mimic constraints`) — no nos afecta, nuestro diseño no usa mimic joints.

### Launch de los controllers (`spawner`)

Creado `robotic_arm_controller/launch/controller.launch.py` (patrón del curso adaptado): arg `is_sim` (default `True`) que en simulación evita levantar `robot_state_publisher`/`ros2_control_node` propios (ya los provee el plugin `gz_ros2_control` dentro de Gazebo), más 3 `Node` de `controller_manager`/`spawner` (`joint_state_broadcaster`, `arm_controller`, `gripper_controller`). Agregado `launch` al `install(DIRECTORY ...)` del `CMakeLists.txt` y los `exec_depend` (`robotic_arm_description`, `robot_state_publisher`, `controller_manager`, `xacro`, `ros2launch`) al `package.xml`.

```bash
# Terminal 1
ros2 launch robotic_arm_description gazebo.launch.py
# Terminal 2
ros2 launch robotic_arm_controller controller.launch.py
```
**Resultado: éxito total.** Los 3 controladores se cargaron y activaron sin errores contra el `controller_manager` de Gazebo: `Loaded` → `Configured and activated` para `gripper_controller`, `joint_state_broadcaster` y `arm_controller`. Cada `spawner` termina limpio después de activar su controlador (comportamiento esperado, es un script de un solo uso). **El brazo queda completamente controlable desde ROS2** — objetivo central de R02 cumplido.

### Primer movimiento real comandado

```bash
ros2 action send_goal /arm_controller/follow_joint_trajectory control_msgs/action/FollowJointTrajectory "{trajectory: {joint_names: [shoulder_pan, shoulder_lift, elbow_flex, wrist_flex, wrist_roll], points: [{positions: [0.3, 0.0, 0.0, 0.0, 0.0], time_from_start: {sec: 3}}]}}"
```
Trayectoria mandada al action `FollowJointTrajectory` de `arm_controller` (solo `shoulder_pan` a 0.3 rad, resto en 0, en 3s), con Gazebo + `gazebo.launch.py` + `controller.launch.py` corriendo. **Resultado: `Goal successfully reached!`, status `SUCCEEDED`.** El brazo se movió en Gazebo tal cual lo pedido. Cadena completa validada: URDF (xacro) → spawn en Gazebo → `ros2_control` activado → controllers spawneados → movimiento real comandado desde ROS2.

### Control interactivo con sliders

Inspirado en `arduinobot_controller` del proyecto de referencia (`slider_control.py` + `slider_controller.launch.py`), adaptado a los nombres reales de joints (5 del brazo + `gripper`, en vez de los 3+1 del curso):

- `robotic_arm_controller/robotic_arm_controller/slider_control.py`: nodo que se suscribe a `/joint_commands` (`sensor_msgs/JointState`) y separa el mensaje en dos `trajectory_msgs/JointTrajectory` — uno a `arm_controller/joint_trajectory` (`positions[:5]`) y otro a `gripper_controller/joint_trajectory` (`positions[5]`), publicados directo por tópico (los `JointTrajectoryController` aceptan comandos por tópico además de por action).
- `robotic_arm_controller/launch/slider_controller.launch.py`: incluye `controller.launch.py`, levanta `joint_state_publisher_gui` **remapeado** (`/joint_states` → `/joint_commands`, reutilizando la ventana de sliders como generador de comandos en vez de lector de estado) y el nodo `slider_control`.
- `CMakeLists.txt`: agregado `ament_cmake_python` + `ament_python_install_package(${PROJECT_NAME})` + `install(PROGRAMS .../slider_control.py DESTINATION lib/${PROJECT_NAME} RENAME slider_control)` (paquete `ament_cmake` con un nodo Python adentro — patrón válido, no hace falta migrar a `ament_python`).
- `package.xml`: agregado `ament_cmake_python` como `buildtool_depend`, más `rclpy`, `sensor_msgs`, `trajectory_msgs`, `joint_state_publisher_gui` como `exec_depend`.

```bash
colcon build
# Terminal 1
ros2 launch robotic_arm_description gazebo.launch.py
# Terminal 2
ros2 launch robotic_arm_controller slider_controller.launch.py
```
**Resultado: funciona.** Ventana de 6 sliders, moviéndolos el brazo reacciona en vivo en Gazebo.

## Cómo levantar la simulación completa (2 terminales)

Con Terminator (split de terminal), parado en `robotic_arm_ws/`:

1. **Terminal 1** — build + Gazebo:

```bash
ros_jazzy
colcon build
. install/setup.zsh
ros2 launch robotic_arm_description gazebo.launch.py
```

`colcon build` libera la terminal al terminar, así que se puede encadenar el `launch` en la misma. Ojo: hace falta sourcear `install/setup.zsh` después del build (`ros_jazzy` solo trae el ROS2 base, no los paquetes del workspace recién compilados). Con Gazebo abierto, configurar las physics del world en `0.01` (step size) en vez de `0.001`, para que la simulación fluya mejor.

2. **Terminal 2** — sliders:

```bash
ros_jazzy
. install/setup.zsh
ros2 launch robotic_arm_controller slider_controller.launch.py
```

No hace falta correr `controller.launch.py` en una terminal aparte: `slider_controller.launch.py` lo incluye como primer paso (`IncludeLaunchDescription` de `controller.launch.py` al principio del archivo), así que ya levanta los 3 controllers (`joint_state_broadcaster`, `arm_controller`, `gripper_controller`) antes de arrancar el nodo de sliders.

### Verificación: `ros2 control list_hardware_interfaces`

Con la simulación corriendo (terminales de arriba activas), en una terminal nueva:

```bash
ros_jazzy
. install/setup.zsh
ros2 control list_hardware_interfaces
```

```
[INFO] [1789673772.174408439] [_ros2cli_27753]: waiting for service /controller_manager/list_hardware_interfaces to become available...
command interfaces
    elbow_flex/position [available] [claimed]
    gripper/position [available] [claimed]
    shoulder_lift/position [available] [claimed]
    shoulder_pan/position [available] [claimed]
    wrist_flex/position [available] [claimed]
    wrist_roll/position [available] [claimed]
state interfaces
    elbow_flex/position
    gripper/position
    shoulder_lift/position
    shoulder_pan/position
    wrist_flex/position
    wrist_roll/position
```

Este comando le pregunta al `controller_manager` qué interfaces de hardware tiene registradas (en este caso, expuestas por el plugin `gz_ros2_control` que hace de "hardware" dentro de Gazebo). Dos categorías:

- **command interfaces**: por donde un controller *escribe* un comando al joint (acá, posición). `[available]` significa que la interfaz existe; `[claimed]` significa que ya hay un controller que la tomó de forma exclusiva — en este caso `arm_controller` y `gripper_controller`, que son los que efectivamente mueven el brazo cuando se usan los sliders.
- **state interfaces**: por donde se *lee* el estado actual del joint. No aparecen como `[claimed]` porque leer no es exclusivo — varios nodos pueden leer la misma interfaz al mismo tiempo (acá la lee `joint_state_broadcaster` para publicar `/joint_states`).

Solo aparecen los 6 joints actuables (5 del brazo + `gripper`); el `virtual_joint` (fijo, `world`→`base_link`) no tiene interfaces porque no es actuable. Sirve como chequeo de salud: si todas las interfaces de comando aparecen `[claimed]`, confirma que `ros2_control` está arriba y los controllers tienen tomado el hardware antes de probar movimiento.

### Verificación: `ros2 control list_hardware_components`

```bash
ros2 control list_hardware_components
```

```
Hardware Component 1
    name: RobotSystem
    type: 
    plugin name: 
    state: id=3 label=active
    read/write rate: 0 Hz
    is_async: False
    command interfaces
        shoulder_pan/position [available] [claimed]
        shoulder_lift/position [available] [claimed]
        elbow_flex/position [available] [claimed]
        wrist_flex/position [available] [claimed]
        wrist_roll/position [available] [claimed]
        gripper/position [available] [claimed]
```

Complementa al comando anterior, pero mirando desde el otro lado: en vez de listar las interfaces sueltas, agrupa todo por **componente de hardware**. Acá aparece uno solo, `RobotSystem`, que es el nombre que le dimos en `<hardware><plugin>` dentro de `robotic_arm_ros2_control.xacro` (la implementación real detrás es `gz_ros2_control/GazeboSimSystem`, el plugin de Gazebo Sim actuando como "hardware" simulado).

- **`state: id=3 label=active`**: el ciclo de vida de `ros2_control` (basado en `rclcpp_lifecycle`) pasó por `unconfigured → inactive → active`; `active` es el único estado en el que el hardware realmente lee/escribe. Si algo falla al iniciar Gazebo, esto se queda en `inactive` o `unconfigured` y ningún joint responde.
- **`read/write rate: 0 Hz`**: estadística que no se está poblando para este hardware simulado (el ritmo real lo marca el `update_rate` del `controller_manager`, no una lectura propia del plugin) — no es un error, es una particularidad de `gz_ros2_control`.
- **`is_async: False`**: el hardware lee/escribe de forma síncrona con el ciclo del `controller_manager`, no en un hilo aparte.
- Repite las mismas 6 command interfaces `[available] [claimed]` que el comando anterior, ahora como "propiedad" de este componente puntual — útil cuando hay más de un hardware component y hace falta saber cuál tiene tomada cada interfaz.

## Próximos pasos

- [x] Crear workspace ROS2 (`robotic_arm_ws/src`)
- [x] Crear paquete ROS2 para el brazo (`robotic_arm_description`)
- [x] Escribir `robotic_arm.urdf.xacro` completo (9 links + 8 joints), validado con `xacro` + `check_urdf`
- [x] Chequeo visual del URDF en RViz (`urdf_tutorial display.launch.py`) — brazo completo, sin errores
- [x] Levantar el modelo en Gazebo (`gazebo.launch.py`, `ros_gz_sim` + spawn + bridge de `/clock`) — se ve bien
- [x] Escribir `robotic_arm_controllers.yaml` (joint_state_broadcaster + arm_controller + gripper_controller)
- [x] Completar `robotic_arm_ros2_control.xacro` (6 joints con command/state interface) y `robotic_arm_gazebo.xacro` (plugin bien formado, sin el wrapper `<xacro>` suelto)
- [x] Agregar `install(DIRECTORY config ...)` al `CMakeLists.txt` de `robotic_arm_controller`
- [x] Confirmar que `ros2_control` levanta bien en Gazebo (`controller_manager` activo, hardware `RobotSystem` inicializado, 6 joints registrados) — revisado log completo
- [x] Crear el launch que levante los controllers (`controller.launch.py`) — los 3 controladores se activan sin errores
- [x] Probar mover el brazo mandando una trayectoria real — `Goal successfully reached!`, se movió correctamente en Gazebo
- [ ] **Confirmado, no solo hipotético:** reemplazar la geometría de `<collision>` (mallas STL de detalle completo) por formas primitivas (cajas/cilindros) — `dartsim` no puede construir colisión desde STL, el brazo no tiene colisión física en ningún link ahora mismo

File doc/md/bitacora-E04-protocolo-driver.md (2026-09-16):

# Bitácora — E04: Cómo comandar el driver de motores vía TX-RX

## Objetivo
Averiguar qué protocolo hay que hablar por TX-RX para comandar el driver de servos (Waveshare Bus Servo Adapter (A)), de cara al firmware puente ESP32 <-> driver.

## Contexto
- E03 ya confirmó que ESP32 y el conector de host del adaptador son compatibles en 3.3V, sin conversor de nivel.
- El adaptador convierte USB a UART mediante el chip **CH343P** (visible en el esquemático `doc/datasheets/Bus Servo Adapter (A)-Sch.pdf`).
- `STServo_Python` ya controla los servos hoy por USB, a través de este mismo adaptador.

## Hallazgo

- Fuente: [components101 — CH343 pinout/datasheet](https://components101.com/ics/ch343-high-speed-usb-to-serial-chip-pinout-datasheet): *"The CH343 is a USB bus converter chip, which converts USB to a high-speed serial UART interface."*
- Esto confirma que el CH343P es un **puente USB-UART transparente** (misma familia de función que un FTDI FT232 o un CP210x), no un traductor de protocolo. No interpreta ni reformatea los bytes que pasan por él.
- Coincide con lo visto en el esquemático: el CH343P expone pines típicos de un puente serie genérico (TXD/RXD/RI/CTS/DSR/DCD/DTR), sin ninguna lógica de protocolo de servos.

**Consecuencia para el diseño:** los bytes que hoy viajan por USB desde `STServo_Python` hacia los servos son *exactamente* los mismos bytes que van a viajar por TX/RX cuando el host sea el ESP32 en vez de la PC. El protocolo a implementar en el ESP32 es el mismo que ya usa el SDK de Python — no hay que inventar ni traducir nada nuevo en el adaptador.

## Ubicación del SDK en el repo

- `servo_control_ui.py` importa `sms_sts` desde `scservo_sdk` (línea ~63-69).
- El paquete `scservo_sdk` no vive como archivo propio del repo: está descomprimido dentro del virtualenv, en `STServo_Python/stservo-env/scservo_sdk/` (no se ve en el explorador de VS Code porque `stservo-env` suele quedar excluido de la búsqueda/gitignored). Nota: en la raíz del venv también aparecen carpetas sueltas `STservo_sdk`, `sms_sts`, `scscl` — probablemente restos de cómo se descomprimió el SDK ahí en vez de instalarlo con pip; no afectan el funcionamiento actual.
- Archivos relevantes dentro de `scservo_sdk/`: `protocol_packet_handler.py` (armado/parseo de tramas — el que se documenta acá), `port_handler.py` (capa serie), `sms_sts.py` (comandos de alto nivel para servos STS/SMS), `scservo_def.py` (constantes: instrucciones, IDs, bits de error).

## Formato de trama (protocolo estilo Feetech/Dynamixel)

Paquete binario simple, sin capa extra. Definido en `protocol_packet_handler.py` y `scservo_def.py`.

| Byte(s) | Campo | Descripción |
|---|---|---|
| 0-1 | `0xFF 0xFF` | Header fijo |
| 2 | ID | ID del servo destino (0-253). `0xFE` (254, `BROADCAST_ID`) = todos |
| 3 | Length | Bytes restantes: instrucción + parámetros + checksum |
| 4 | Instrucción | Ver tabla de instrucciones |
| 5..N-1 | Parámetros | Datos según instrucción (p. ej. dirección de registro + valor) |
| N | Checksum | `~(ID + Length + Instrucción + Parámetros) & 0xFF` (complemento a 1 de la suma, bytes 2 a N-1) |

Paquete de respuesta (status packet) del servo: misma estructura, pero el byte 4 es un **byte de error** (bit 0=voltaje, bit 1=ángulo, bit 2=sobretemperatura, bit 3=sobrecorriente, bit 5=sobrecarga; 0 = sin error) en vez de instrucción.

### Instrucciones (`scservo_def.py`)

| Valor | Nombre | Uso |
|---|---|---|
| 1 | `INST_PING` | "¿Estás ahí?" — responde con el modelo |
| 2 | `INST_READ` | Leer un registro (ej. posición actual) |
| 3 | `INST_WRITE` | Escribir un registro (ej. posición objetivo) — la más usada |
| 4 | `INST_REG_WRITE` | Como WRITE pero diferido, se ejecuta al llegar un ACTION |
| 5 | `INST_ACTION` | Dispara los REG_WRITE pendientes (sincroniza varios servos) |
| 130 (0x82) | `INST_SYNC_READ` | Leer el mismo registro de varios servos en un solo paquete |
| 131 (0x83) | `INST_SYNC_WRITE` | Escribir valores distintos a varios servos en un solo paquete (lo que usa la UI para mover el brazo completo) |

### Registros usados por `WritePosEx`/`SyncWritePosEx` (`sms_sts.py`)

Bloque de 7 registros contiguos en SRAM, arrancando en `SMS_STS_ACC = 41`:

| Offset desde ACC | Dirección | Registro | Contenido |
|---|---|---|---|
| +0 | 41 (0x29) | ACC | Aceleración |
| +1 | 42 | GOAL_POSITION_L | Posición objetivo, byte bajo |
| +2 | 43 | GOAL_POSITION_H | Posición objetivo, byte alto |
| +3 | 44 | GOAL_TIME_L | Sin usar en este SDK → `0x00` |
| +4 | 45 | GOAL_TIME_H | Sin usar → `0x00` |
| +5 | 46 | GOAL_SPEED_L | Velocidad, byte bajo |
| +6 | 47 | GOAL_SPEED_H | Velocidad, byte alto |

Los valores de 16 bits van en **little-endian** (byte bajo primero) — así arman `scs_lobyte`/`scs_hibyte` en `protocol_packet_handler.py` cuando `scs_end=0` (el caso de `sms_sts`).

## Ejemplo 1 — WRITE simple: servo ID 1 a posición 2048, velocidad 500, acc 50

Valores: `acc=50 (0x32)`, `position=2048 (0x0800)` → posL=`0x00`, posH=`0x08`; `speed=500 (0x01F4)` → speedL=`0xF4`, speedH=`0x01`.

**Hexadecimal del paquete completo:**
```
FF FF 01 0A 03 29 32 00 08 00 00 F4 01 99
```

**Parseado:**

| Bytes (hex) | Campo | Valor |
|---|---|---|
| `FF FF` | Header | fijo |
| `01` | ID | servo 1 |
| `0A` | Length | 10 (INST + ADDR + 7 datos + checksum) |
| `03` | Instrucción | `INST_WRITE` |
| `29` | Parámetro 0 | dirección de inicio = 41 (ACC) |
| `32` | Parámetro 1 | acc = 50 |
| `00 08` | Parámetro 2-3 | posición = 0x0800 = 2048 (little-endian: L=00, H=08) |
| `00 00` | Parámetro 4-5 | goal_time (sin usar) = 0 |
| `F4 01` | Parámetro 6-7 | velocidad = 0x01F4 = 500 (L=F4, H=01) |
| `99` | Checksum | `~(01+0A+03+29+32+00+08+00+00+F4+01) & 0xFF` = `~0x66 & 0xFF` = `0x99` |

El servo responde con un status packet (mismo formato, byte 4 = error 0x00 si todo OK) porque `WritePosEx` usa `writeTxRx` (espera respuesta), a diferencia de `SyncWritePosEx` que es fire-and-forget.

## Ejemplo 2 — SYNC_WRITE: 2 servos en un solo paquete

Servo 1: posición 2048 (0x0800), velocidad 500 (0x01F4), acc 50 (0x32) — igual que arriba.
Servo 2: posición 1024 (0x0400), velocidad 300 (0x012C), acc 30 (0x1E).

**Hexadecimal del paquete completo:**
```
FF FF FE 14 83 29 07 01 32 00 08 00 00 F4 01 02 1E 00 04 00 00 2C 01 B9
```

**Parseado:**

| Bytes (hex) | Campo | Valor |
|---|---|---|
| `FF FF` | Header | fijo |
| `FE` | ID | `BROADCAST_ID` (0xFE) — un solo paquete para todos |
| `14` | Length | 20 (INST + start_addr + data_len + 2×8 bytes de servo + checksum) |
| `83` | Instrucción | `INST_SYNC_WRITE` (131) |
| `29` | start_address | 41 (ACC) — mismo bloque de registros que en WRITE simple |
| `07` | data_length | 7 bytes de datos por servo |
| `01 32 00 08 00 00 F4 01` | Bloque servo 1 | ID=1, acc=50, pos=2048 (00 08), time=0, speed=500 (F4 01) |
| `02 1E 00 04 00 00 2C 01` | Bloque servo 2 | ID=2, acc=30, pos=1024 (00 04), time=0, speed=300 (2C 01) |
| `B9` | Checksum | `~(FE+14+83+29+07+ suma de los 16 bytes de datos) & 0xFF` = `~0x46 & 0xFF` = `0xB9` |

**Nada responde a este paquete** (broadcast → sin status packet, ver `protocol_packet_handler.py:234-236`). Para el brazo completo (6 servos) el paquete se arma igual, solo agregando más bloques de 8 bytes (uno por servo) antes del checksum.

## Conclusión

Protocolo identificado y documentado por completo: header fijo `0xFF 0xFF`, ID, length, instrucción, parámetros, checksum de complemento a 1. Es el mismo protocolo que ya habla `STServo_Python` por USB — el firmware del ESP32 tiene que armar/parsear exactamente estas mismas tramas para reenviarlas por su UART hacia el driver.

## Próximos pasos

- [x] Confirmar si el adaptador traduce protocolo o es un puente transparente — **es transparente** (CH343P)
- [x] Identificar el protocolo exacto que usa `STServo_Python` para hablar con los servos — `scservo_sdk/protocol_packet_handler.py`
- [x] Documentar el formato de trama (header, ID, instrucción, checksum, etc.)
- [x] Revisar el formato de `INST_SYNC_WRITE` en detalle, con ejemplos en hexadecimal parseados byte a byte

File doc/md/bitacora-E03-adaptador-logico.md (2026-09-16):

# Bitácora — E03: ¿Hace falta adaptador lógico entre ESP32 y driver de servos?

## Objetivo
Averiguar si es necesario un conversor de nivel lógico entre el ESP32 y el driver de servos (Waveshare Bus Servo Adapter (A)) antes de cablear la UART entre ambos, y conseguir uno si hiciera falta.

## Contexto
- Niveles del ESP32 ya confirmados en [E02](bitacora-E02-niveles.md): 0V (LOW) / 3.3V (HIGH), CMOS estándar.
- La documentación pública de Waveshare (wiki + `docs.waveshare.com/Bus_Servo_Adapter_A`) especifica la alimentación de potencia (9~12.6V, o 5~8.4V) pero **no indica explícitamente** el nivel lógico de los pines UART de host.
- El ejemplo de wiring del fabricante muestra la interfaz UART conectada directo a una Raspberry Pi Zero (GPIO a 3.3V, no tolerante a 5V) sin level shifter visible — indicio fuerte pero no concluyente.

## Análisis del esquemático
Esquemático disponible en `doc/datasheets/Bus Servo Adapter (A)-Sch.pdf`. Hallazgo con evidencia directa (no inferencia):

- **U2 (AMS1117-3.3)**: regulador que genera el riel **3V3** de la placa a partir de la alimentación USB/5V.
- **U3 (SN74LVC1G126)** y **U4 (SN74LVC1G125)**: buffers de línea que manejan las señales `U1TXD`/`U1RXD` hacia el conector de host (H4, el que se cablea al ESP32). Ambos tienen su pin **VCC alimentado del riel 3V3**, no de los 5V de VDDUSB ni del DC_IN de los servos.
- El riel de 5V de la placa solo alimenta la etapa USB (chip USB-UART CH343P) y la conversión de potencia hacia los servos — nunca las líneas de datos del conector de host.

**Conclusión del esquemático:** las líneas TXD/RXD expuestas al host (ESP32) están ancladas a lógica 3.3V, igual que el ESP32.

Detalle adicional (no afecta el nivel de tensión, pero relevante para el firmware): hay un transistor Q1 (MMBT3906) con una señal `TXEN` en la misma etapa, que parece un circuito de auto-detección/control de dirección del buffer (se activa cuando el host transmite). Si el ESP32 no recibe nada la primera vez, revisar esto antes que la alimentación.

## Conclusión

**No hace falta adaptador/conversor de nivel lógico.** ESP32 (3.3V CMOS, confirmado en E02) y el conector de host del Bus Servo Adapter (A) (3.3V TTL, confirmado por esquemático: U2/U3/U4) son directamente compatibles. Se puede cablear TX-RX / RX-TX directo entre ambos.

## Próximos pasos

- [x] Revisar documentación pública de Waveshare (wiki + docs) — nivel lógico no especificado explícitamente
- [x] Analizar esquemático oficial (`Bus Servo Adapter (A)-Sch.pdf`) — confirmado riel 3V3 en la etapa de buffers de host (U2/U3/U4)
- [x] Concluir si hace falta conversor de nivel — **no hace falta**
- [ ] (Recomendado antes de cablear en firme) Verificar con multímetro la tensión de reposo (idle HIGH) del TX del adaptador, como chequeo final de hardware

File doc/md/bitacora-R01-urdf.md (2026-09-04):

# Bitácora — R01: URDF del proyecto SO-ARM100 para Gazebo/ROS2

## Objetivo

Averiguar si el proyecto en el que está basado este brazo (`TheRobotStudio/SO-ARM100`) tiene un URDF disponible para simular con Gazebo ROS2.

## Investigación realizada

- Repo: https://github.com/TheRobotStudio/SO-ARM100
- Se listó el árbol completo del repo vía GitHub API (`git/trees/main?recursive=1`) buscando archivos `.urdf`, `.xacro`, `.sdf`, `.world` y referencias a `ros2`/`gazebo`.
- Se leyó `Simulation/README.md` del repo para confirmar el uso previsto de los archivos.

## Hallazgos

- La carpeta `Simulation/` contiene:
  - **SO100**: `Simulation/SO100/so100.urdf` + mallas STL en `assets/`.
  - **SO101**: `Simulation/SO101/so101_new_calib.urdf` y `so101_old_calib.urdf` (dos calibraciones distintas), más mallas STL.
  - **SO101** además tiene archivos **MJCF** (MuJoCo): `scene.xml`, `joints_properties.xml`, `so101_new_calib.xml`, `so101_old_calib.xml`.
- No se encontró ningún archivo `.sdf`, `.world`, ni estructura de paquete ROS2 (`package.xml`, `launch/`, plugins `gazebo_ros2_control`).
- El README oficial de `Simulation/` solo documenta visualizar los URDF con [`rerun`](https://www.rerun.io/) (plugin URDF), no menciona Gazebo en ningún punto.

## Conclusión

**Sí existe URDF** (para SO100 y SO101, este último con dos variantes de calibración), pero es un URDF "crudo": geometría + juntas + mallas, sin nada específico de Gazebo. No hay paquete ROS2 ni plugins de control armados — eso queda para R02 (armar/generar lo que falte para levantarlo en Gazebo).

URDF a usar como base: **`Simulation/SO101/so101_new_calib.urdf`** (calibración nueva, la que corresponde al brazo armado).

## Próximos pasos

- [x] Confirmar si el repo tiene URDF
- [x] Identificar cuál URDF usar como base (SO101, calibración nueva)
- [ ] R02: armar paquete ROS2 + adaptaciones para levantar el URDF en Gazebo

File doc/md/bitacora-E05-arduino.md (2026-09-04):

# Bitácora — E05: Probar TX-RX ESP32 con Arduino Nano

## Objetivo
Probar el código UART del ESP32 (de E01) comunicándose con un Arduino Nano, programando este último para enviar y recibir mensajes por los pines TX-RX.

## Decisiones tomadas

- **Hace falta un conversor de nivel lógico bidireccional entre ambas placas.** El ESP32 trabaja con lógica de 3.3V (confirmado en E02: VL=0V, VH=3.29V) y el Arduino Nano trabaja con lógica de 5V — no se pueden conectar TX-RX directo entre ambos.
- **Módulo disponible: HW-221**, con un chip marcado **YF08E**.
  - Investigado y confirmado: **YF08E no es un chip distinto ni un clon** — es el código de marcado (topside marking) que Texas Instruments graba en el paquete TSSOP-20 del **TXS0108E**, su traductor de nivel bidireccional de 8 bits. El datasheet correspondiente es el oficial de TI para el TXS0108E.
  - Guardado en `doc/datasheets/txs0108e.pdf`.
  - Specs relevantes: VCCA acepta 1.2V–3.6V, VCCB acepta 1.65V–5.5V, traducción bidireccional no inversora, compatible con UART/I2C/SPI — encaja para el par 3.3V (ESP32) / 5V (Arduino Nano).
- **Pin OE (Output Enable) del TXS0108E:** entrada digital referenciada a VCCA. En alto habilita la traducción normal en todos los pines A/B; en bajo, todos los pines A1-A8/B1-B8 pasan a alta impedancia (chip "apagado" a nivel de señal). Su propósito según el datasheet es evitar glitches durante power-up/power-down.
  - Verificado con el multímetro en modo continuidad en el módulo HW-221: **OE está puenteado a VCCA en la placa** → queda siempre habilitado apenas se alimenta el módulo, no requiere manejo aparte.
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

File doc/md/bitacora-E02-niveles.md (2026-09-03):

# Bitácora — E02: Niveles de voltaje TX/RX del ESP32

## Objetivo
Medir el voltaje mínimo (nivel LOW) y máximo (nivel HIGH) de las señales digitales de salida del ESP32, para conocer sus características eléctricas antes de interfacearlo con el driver de motores (relacionado con E03: evaluar si hace falta un conversor lógico).

## Decisiones tomadas

- **El analizador lógico U6041 (24MHz/8CH) no sirve para esta tarea.** Es puramente digital por umbral, no mide voltaje analógico: según su datasheet (`doc/datasheets/logical-analyzer-U6041.pdf`), el rango de entrada es 0–5.5V con umbral fijo en 1.5V — por debajo se interpreta `LOW`, por arriba `HIGH`. No devuelve ningún valor numérico de voltios.
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

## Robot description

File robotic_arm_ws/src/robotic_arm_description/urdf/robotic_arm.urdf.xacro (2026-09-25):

<?xml version="1.0"?>
<robot xmlns:xacro="http://www.ros.org/wiki/xacro" name="robotic_arm">

    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
    <xacro:arg name="is_ignition" default="false"/>

    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
    <xacro:arg name="is_sim" default="true"/>

    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
    <xacro:include filename="$(find robotic_arm_description)/urdf/robotic_arm_gazebo.xacro" />

    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
    <xacro:include filename="$(find robotic_arm_description)/urdf/robotic_arm_ros2_control.xacro" />

	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
	<xacro:property name="effort" value="10" />
	<xacro:property name="velocity" value="10" />

	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
	<xacro:macro name="default_inertial" params="mass">
		<inertial>
			<origin xyz="0 0 0" rpy="0 0 0"/>
			<mass value="${mass}" />
			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
		</inertial>
	</xacro:macro>

	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
	<link name="world"/>
	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
	<link name="base_link">
		<inertial>
			<origin xyz="0.0137179 -5.19711e-05 0.0334843" rpy="0 0 0"/>
			<mass value="0.147"/>
			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
		</inertial>
		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
	</link>

	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
	<link name="shoulder_link">
		<inertial>
			<origin xyz="-0.0307604 -1.66727e-05 -0.0252713" rpy="0 0 0"/>
			<mass value="0.100006"/>
			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
		</inertial>
		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
	</link>

	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
	<link name="upper_arm_link">
		<inertial>
			<origin xyz="-0.0898471 -0.00838224 0.0184089" rpy="0 0 0"/>
			<mass value="0.103"/>
			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
		</inertial>
		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
	</link>

	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
	<link name="lower_arm_link">
		<inertial>
			<origin xyz="-0.0980701 0.00324376 0.0182831" rpy="0 0 0"/>
			<mass value="0.104"/>
			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
		</inertial>
		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
	</link>

	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
	<link name="wrist_link">
		<inertial>
			<origin xyz="-0.000103312 -0.0386143 0.0281156" rpy="0 0 0"/>
			<mass value="0.079"/>
			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
		</inertial>
		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
	</link>

	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
	<link name="gripper_link">
		<inertial>
			<origin xyz="0.000213627 0.000245138 -0.025187" rpy="0 0 0"/>
			<mass value="0.087"/>
			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
		</inertial>
		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
	</link>

	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
	<link name="gripper_frame_link">
		<origin xyz="0 0 0" rpy="0 -0 0"/>
		<inertial>
			<origin xyz="0 0 0" rpy="0 0 0"/>
			<mass value="1e-9"/>
			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
		</inertial>
	</link>

	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
	<link name="moving_jaw_so101_v1_link">
		<inertial>
			<origin xyz="-0.00157495 -0.0300244 0.0192755" rpy="0 0 0"/>
			<mass value="0.012"/>
			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
		</inertial>
		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
	</link>

	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
	<joint name="virtual_joint" type="fixed">
		<parent link="world"/>
		<child link="base_link"/>
		<origin xyz="0 0 0" rpy="0 0 0"/>
	</joint>

	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
	<joint name="shoulder_pan" type="revolute">
		<origin xyz="0.0388353 -8.97657e-09 0.0624" rpy="3.14159 4.18253e-17 -3.14159"/>
		<parent link="base_link"/>
		<child link="shoulder_link"/>
		<axis xyz="0 0 1"/>
		<limit effort="${effort}" velocity="${velocity}" lower="-1.91986" upper="1.91986"/>
	</joint>

	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
	<joint name="shoulder_lift" type="revolute">
		<origin xyz="-0.0303992 -0.0182778 -0.0542" rpy="-1.5708 -1.5708 0"/>
		<parent link="shoulder_link"/>
		<child link="upper_arm_link"/>
		<axis xyz="0 0 1"/>
		<limit effort="${effort}" velocity="${velocity}" lower="-1.74533" upper="1.74533"/>
	</joint>

	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
	<joint name="elbow_flex" type="revolute">
		<origin xyz="-0.11257 -0.028 1.73763e-16" rpy="-3.63608e-16 8.74301e-16 1.5708"/>
		<parent link="upper_arm_link"/>
		<child link="lower_arm_link"/>
		<axis xyz="0 0 1"/>
		<limit effort="${effort}" velocity="${velocity}" lower="-1.69" upper="1.69"/>
	</joint>

	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
	<joint name="wrist_flex" type="revolute">
		<origin xyz="-0.1349 0.0052 3.62355e-17" rpy="4.02456e-15 8.67362e-16 -1.5708"/>
		<parent link="lower_arm_link"/>
		<child link="wrist_link"/>
		<axis xyz="0 0 1"/>
		<limit effort="${effort}" velocity="${velocity}" lower="-1.65806" upper="1.65806"/>
	</joint>

	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
	<joint name="wrist_roll" type="revolute">
		<origin xyz="5.55112e-17 -0.0611 0.0181" rpy="1.5708 0.0486795 3.14159"/>
		<parent link="wrist_link"/>
		<child link="gripper_link"/>
		<axis xyz="0 0 1"/>
		<limit effort="${effort}" velocity="${velocity}" lower="-2.74385" upper="2.84121"/>
	</joint>

	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
	<joint name="gripper" type="revolute">
		<origin xyz="0.0202 0.0188 -0.0234" rpy="1.5708 -5.24284e-08 -1.41553e-15"/>
		<parent link="gripper_link"/>
		<child link="moving_jaw_so101_v1_link"/>
		<axis xyz="0 0 1"/>
		<limit effort="${effort}" velocity="${velocity}" lower="-0.174533" upper="1.74533"/>
	</joint>

	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
	<joint name="gripper_frame_joint" type="fixed">
		<origin xyz="-0.0079 -0.000218121 -0.0981274" rpy="0 3.14159 0"/>
		<parent link="gripper_link"/>
		<child link="gripper_frame_link"/>
	</joint>
</robot>

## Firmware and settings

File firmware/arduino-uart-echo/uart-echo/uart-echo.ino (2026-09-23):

// Echo por serial
#define LED 4// 13-BOARDLED 4-YELLOWLED

String input = "";
void setup() {
  Serial.begin(115200);
  pinMode(LED,OUTPUT);
  digitalWrite(LED,LOW);
}

void loop() {
  while (Serial.available() > 0) {
    char c = Serial.read();

    if (c == '\n') {
      if( input == "ON") {
        digitalWrite(LED,HIGH);
      } else if (input == "OFF") {
        digitalWrite(LED,LOW);
      }
      
      // Línea completa recibida
      Serial.println(input);
      input = "";// limpiar para la próxima
    } else {
      input += c;
    }
  }
}

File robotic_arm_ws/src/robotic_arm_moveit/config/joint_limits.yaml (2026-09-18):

# joint_limits.yaml allows the dynamics properties specified in the URDF to be overwritten or augmented as needed

# For beginners, we downscale velocity and acceleration limits.
# You can always specify higher scaling factors (<= 1.0) in your motion requests.  # Increase the values below to 1.0 to always move at maximum speed.
default_velocity_scaling_factor: 0.1
default_acceleration_scaling_factor: 0.1

# Specific joint properties can be changed with the keys [max_position, min_position, max_velocity, max_acceleration]
# Joint limits can be turned off with [has_velocity_limits, has_acceleration_limits]
joint_limits:
  shoulder_pan:
    has_velocity_limits: true
    max_velocity: 4.24
    has_acceleration_limits: true
    max_acceleration: 6.9
  shoulder_lift:
    has_velocity_limits: true
    max_velocity: 4.24
    has_acceleration_limits: true
    max_acceleration: 6.9
  elbow_flex:
    has_velocity_limits: true
    max_velocity: 4.24
    has_acceleration_limits: true
    max_acceleration: 6.9
  wrist_flex:
    has_velocity_limits: true
    max_velocity: 4.24
    has_acceleration_limits: true
    max_acceleration: 6.9
  wrist_roll:
    has_velocity_limits: true
    max_velocity: 4.24
    has_acceleration_limits: true
    max_acceleration: 6.9
  gripper:
    has_velocity_limits: true
    max_velocity: 4.24
    has_acceleration_limits: true
    max_acceleration: 6.9

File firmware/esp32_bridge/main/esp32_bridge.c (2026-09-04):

#include <stdio.h>
#include <string.h>
#include "freertos/FreeRTOS.h"
#include "freertos/task.h"
#include "sdkconfig.h"
#include "driver/uart.h"
#include "driver/uart_vfs.h"
#include "esp_log.h"

#define BRIDGE_TXD CONFIG_EXAMPLE_UART_TXD // G26
#define BRIDGE_RXD CONFIG_EXAMPLE_UART_RXD // G25
#define BRIDGE_RTS (UART_PIN_NO_CHANGE)
#define BRIDGE_CTS (UART_PIN_NO_CHANGE)

#define BRIDGE_UART_PORT CONFIG_EXAMPLE_UART_PORT_NUM
#define BRIDGE_BAUD_RATE CONFIG_EXAMPLE_UART_BAUD_RATE // set to 9600 via menuconfig to match the Nano's SoftwareSerial
#define BRIDGE_TASK_STACK_SIZE CONFIG_EXAMPLE_TASK_STACK_SIZE

#define STX 0x02
#define ETX 0x03

// Mirrors the Nano's rcvBuffer capacity (arduino-uart-test.ino BUFFER_LEN),
// which holds STX + data + ETX (the LRC is read separately, not buffered).
#define NANO_BUFFER_LEN 32
#define MAX_DATA_LEN (NANO_BUFFER_LEN - 2)
#define LINE_BUF_LEN (MAX_DATA_LEN + 1) // +1 for fgets' terminating '\0'
#define FRAME_BUF_LEN (MAX_DATA_LEN + 3) // STX + data + ETX + LRC

static const char *TAG = "ESP32-BRIDGE";

// Reads a line typed on the USB monitor (stdin), frames it as
// STX + data + ETX + LRC (same protocol the Nano parses), and forwards it
// over UART2. Doesn't interpret the text at all -- that's the Nano's job.
static void stdin_to_nano_task(void *arg)
{
    char line[LINE_BUF_LEN];
    uint8_t frame[FRAME_BUF_LEN];

    while (1) {
        if (fgets(line, sizeof(line), stdin) == NULL) {
            vTaskDelay(10 / portTICK_PERIOD_MS);
            continue;
        }

        size_t len = strlen(line);
        while (len > 0 && (line[len - 1] == '\n' || line[len - 1] == '\r')) {
            line[--len] = '\0';
        }
        if (len == 0) {
            continue;
        }
        if (len > MAX_DATA_LEN) {
            len = MAX_DATA_LEN; // truncate to fit the Nano's rcvBuffer
        }

        ESP_LOGI(TAG, "Echo: \"%.*s\"", (int)len, line);

        uint8_t lrc = 0;
        size_t frame_len = 0;

        frame[frame_len++] = STX; // STX itself is not part of the LRC

        for (size_t i = 0; i < len; i++) {
            uint8_t b = (uint8_t)line[i];
            frame[frame_len++] = b;
            lrc ^= b;
        }

        frame[frame_len++] = ETX;
        lrc ^= ETX;

        frame[frame_len++] = lrc;

        uart_write_bytes(BRIDGE_UART_PORT, (const char *)frame, frame_len);
        ESP_LOGI(TAG, "Sent %d bytes to Nano: \"%.*s\"", (int)frame_len, (int)len, line);
    }
}

// Reads whatever the Nano sends back over UART2 (e.g. an ACK) and logs it.
// Accumulates bytes until '\n' instead of logging whatever happens to be in
// the ring buffer at read time -- uart_read_bytes returns as soon as
// anything is available, so a slow SoftwareSerial transmission on the
// Nano's side could otherwise get split across reads and logged as garbage.
static void nano_to_stdout_task(void *arg)
{
    char line[64];
    size_t line_len = 0;
    uint8_t byte;

    while (1) {
        int got = uart_read_bytes(BRIDGE_UART_PORT, &byte, 1, 200 / portTICK_PERIOD_MS);
        if (got <= 0) {
            if (line_len > 0) {
                line[line_len] = '\0';
                ESP_LOGW(TAG, "Nano (no newline within 200ms, showing what arrived): \"%s\"", line);
                line_len = 0;
            }
            continue;
        }

        if (byte == '\n') {
            if (line_len > 0 && line[line_len - 1] == '\r') {
                line_len--;
            }
            line[line_len] = '\0';
            ESP_LOGI(TAG, "Nano: %s", line);
            line_len = 0;
            continue;
        }

        if (line_len < sizeof(line) - 1) {
            line[line_len++] = (char)byte;
        }
    }
}

// Console stdin defaults to non-blocking, per-character reads, which makes
// fgets() return as soon as the RX FIFO momentarily empties instead of
// waiting for '\n'. Switching stdin to the interrupt-driven UART driver
// makes reads properly blocking, so a whole typed line arrives together.
static void configure_stdin_blocking(void)
{
    if (uart_is_driver_installed((uart_port_t)CONFIG_ESP_CONSOLE_UART_NUM)) {
        return;
    }
    setvbuf(stdin, NULL, _IONBF, 0);
    ESP_ERROR_CHECK(uart_driver_install((uart_port_t)CONFIG_ESP_CONSOLE_UART_NUM, 256, 0, 0, NULL, 0));
    uart_vfs_dev_use_driver(CONFIG_ESP_CONSOLE_UART_NUM);
    uart_vfs_dev_port_set_rx_line_endings(CONFIG_ESP_CONSOLE_UART_NUM, ESP_LINE_ENDINGS_CR);
    uart_vfs_dev_port_set_tx_line_endings(CONFIG_ESP_CONSOLE_UART_NUM, ESP_LINE_ENDINGS_CRLF);
}

void app_main(void)
{
    configure_stdin_blocking();

    uart_config_t uart_config = {
        .baud_rate = BRIDGE_BAUD_RATE,
        .data_bits = UART_DATA_8_BITS,
        .parity    = UART_PARITY_DISABLE,
        .stop_bits = UART_STOP_BITS_1,
        .flow_ctrl = UART_HW_FLOWCTRL_DISABLE,
        .source_clk = UART_SCLK_DEFAULT,
    };

    ESP_ERROR_CHECK(uart_driver_install(BRIDGE_UART_PORT, 256, 0, 0, NULL, 0));
    ESP_ERROR_CHECK(uart_param_config(BRIDGE_UART_PORT, &uart_config));
    ESP_ERROR_CHECK(uart_set_pin(BRIDGE_UART_PORT, BRIDGE_TXD, BRIDGE_RXD, BRIDGE_RTS, BRIDGE_CTS));

    xTaskCreate(stdin_to_nano_task, "stdin_to_nano", BRIDGE_TASK_STACK_SIZE, NULL, 10, NULL);
    xTaskCreate(nano_to_stdout_task, "nano_to_stdout", BRIDGE_TASK_STACK_SIZE, NULL, 10, NULL);
}

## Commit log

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2026-06-05 add MATRIZ DE TRAZABILIDAD
    [MATRIZ DE TRAZABILIDAD.xlsx]
2026-06-12 add csv
    [MATRIZ DE TRAZABILIDAD - Hoja 1.csv]
2026-06-12 doc: update MATRIZ DE TRAZABILIDAD
    [MATRIZ DE TRAZABILIDAD - Hoja 1.csv, MATRIZ DE TRAZABILIDAD.csv, MATRIZ DE TRAZABILIDAD.xlsx]
2026-06-12 doc: add MATRIZ DE TRAZABILIDAD ods
    [MATRIZ DE TRAZABILIDAD - RIESGOS.ods]
2026-06-12 doc: add MATRIZ DE TRAZABILIDAD
    [MATRIZ DE TRAZABILIDAD_2.csv]
2026-06-12 doc: delete unused files
    [MATRIZ DE TRAZABILIDAD - RIESGOS.ods, MATRIZ DE TRAZABILIDAD_2.csv]
2026-06-12 doc: update MTZ TRAZABILIDAD
    [MATRIZ DE TRAZABILIDAD 2.csv]
2026-06-12 doc: rename tables
    [MATRIZ_DE_TRAZABILIDAD.csv]
2026-06-15 doc: add Requisitos - Alegre Ezequiel - v1.0.pdf
    Este archivo es el compartido con los docentes.
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2026-06-26 3d: add 3d models to print
    [Ender_Follower_SO101.3mf, test_gauges_2.3mf]
2026-07-02 doc: agregar archivos g_code
    [Ender_Follower_SO101_sz102.3mf, test_Base_SO101.3mf]
2026-07-24 add STServo_Python
    [ST3215 memory register map-EN.xls, pyvenv.cfg]
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2026-08-06 update 3d models
    [Ender_Follower_SO101_sz102.3mf]
2026-08-06 chore: untrack virtualenv and local editor state
    [pyvenv.cfg]
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2026-08-07 fix: corregir convención de signo del OFS (BIT11) en la calibración
    El OFS (Position correction) del STS3215 es sign-magnitude con BIT11 como
    bit de signo; la fórmula correcta es OFS_new = (pos + OFS - target) mod 4096.
    Se agrega tolerancia de ±2 cuentas en la verificación del homing.
    [calibrate-arm.py, calibrate_servo_offset.py]
2026-08-07 feat: sliders 0-100 del rango calibrado, Home, Record/Apply y perfil de movimiento en la UI
    La UI ahora comanda cada servo en porcentaje del rango total calibrado
    (calibration.json), con botones Home (pose zero al 50%), Record/Apply de
    poses (pose.json), control en vivo de velocidad/aceleración (movimientos
    suaves), snap del slider a la posición real al conectar y orden de filas
    invertido para espejar el brazo físico.
    [servo_control_ui.py]
2026-08-10 feat: grabación y reproducción de trayectorias y modo Free (torque off) en la UI
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2026-09-01 feat(doc): agregar PLAN.ods y script de exportación a CSV por hoja
    Script ods_to_csv.py convierte cada hoja del ODS en un CSV independiente
    (solo lectura por defecto), con confirmación previa a sobreescribir.
    [CALIDAD.csv, GANTT.csv, PLAN.ods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]
2026-09-01 chore: clean files
    [MATRIZ_DE_TRAZABILIDAD.csv]
2026-09-01 feat(firmware): add ESP32 blink example project
    Basic ESP-IDF blink firmware with devcontainer setup. Adds
    .vscode/settings.json to .gitignore since it holds machine-specific
    absolute paths (IDF install, toolchain, clangd binary).
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2026-09-04 feat(firmware): implement Nano STX/FS/ETX/LRC parser for E05
    Standalone parser validated over USB with send_cmd.py: ON/OFF commands
    control the LED on D4 in both directions. Fixes an unreachable FULL_PKG
    state — processing now runs inline inside the LRC-match branch instead
    of waiting for a switch re-evaluation that never comes on the last byte.
    Claude-Session: https://claude.ai/code/session_012PeLFUkqxQwKRtGCBgrPsp
    [arduino-uart-test.ino, send_cmd.py]
2026-09-04 docs(E05): reassign UART2 pins from G17/G16 to G25/G26
    Moved to the other physical side of the board for wiring convenience.
    Confirmed via ESP32-WROOM-32 datasheet (sec 4.2.3, GPIO Matrix) that
    UART2 has no hardware pin binding, and G25/G26 are valid (not
    strapping, not SPI flash pins, not input-only like G34/G35).
    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
2026-09-04 fix(docs): correct E05 TX/RX swap, G26=TX / G25=RX
    Previous commit had it backwards. Verified against the actual
    firmware/uart_test/sdkconfig (CONFIG_EXAMPLE_UART_TXD=26,
    CONFIG_EXAMPLE_UART_RXD=25) instead of trusting the prior note.
    Wiring the doc as originally written would have paired TX-to-TX
    on the HW-221 A1/B1 channel, risking driver contention.
    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
2026-09-04 docs(E05): move Nano SoftwareSerial from D2/D3 to A4/A5
    Routing convenience on the protoboard. A0-A5 on the Nano are full
    digital I/O (D14-D19), so SoftwareSerial works the same; A6/A7 were
    ruled out as analog-input-only (no digital output buffer). Noted A4/A5
    default to I2C SDA/SCL for future reference.
    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
2026-09-04 feat(firmware): scaffold esp32_bridge project for E05 USB<->UART2 bridge
    Created via idf.py create-project and copied from uart_test.c as a
    starting point (still the original echo-on-UART2 logic, bridge logic
    not implemented yet). menuconfig set to TXD=26/RXD=25 to match the
    E05 bitácora wiring.
    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
2026-09-04 feat(firmware): implement ESP32 stdin<->UART2 bridge for E05
    Two FreeRTOS tasks: stdin_to_nano_task reads a line from the USB
    monitor, frames it as STX+data+ETX+LRC (same protocol the Nano
    parses) and forwards it over UART2 without interpreting it;
    nano_to_stdout_task logs whatever comes back (the ACK). Frame is
    built with an explicit length counter rather than strcat/strlen, so
    an LRC byte of 0x00 can't truncate it. Baud hardcoded to 9600 since
    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
2026-09-04 fix(firmware): use CONFIG_EXAMPLE_UART_BAUD_RATE instead of hardcoded 9600
    menuconfig was updated to 9600 to match the Nano's SoftwareSerial, so
    the Kconfig macro is now correct and consistent with how TXD/RXD/PORT
    are already handled.
    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
    [esp32_bridge.c]
2026-09-04 feat(firmware): send ACK from Nano and listen on Serial1 for E05 bridge
    loop() now reads from Serial1 (SoftwareSerial, A4/A5) instead of Serial
    (USB) -- it needs to receive frames from the ESP32 bridge through the
    HW-221, not from a directly-attached PC. Serial stays for USB debug
    logs only. Added a DEBUG_STANDALONE_USB compile flag to switch back to
    reading from Serial for standalone testing with send_cmd.py.
    processCommand now replies over Serial1 with ACK:ON/ACK:OFF/NACK:UNKNOWN.
    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
2026-09-04 fix(firmware): make ESP32 stdin blocking and assemble Nano replies by line
    Two bugs found during E05 end-to-end testing:
    - stdin defaulted to non-blocking per-character reads, so fgets()
    returned as soon as the RX FIFO momentarily emptied instead of
    waiting for '\n' -- typing "ON" sent "O" and "N" as separate frames.
    Fixed by installing a real UART driver on the console UART and
    switching the VFS to driver-backed blocking reads (official IDF
    pattern from protocol_examples_common/stdin_out.c).
    - nano_to_stdout_task logged whatever was in the UART2 ring buffer at
    read time instead of a full line, splitting slow SoftwareSerial
    replies across log lines. Now accumulates bytes until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
    [esp32_bridge.c]
2026-09-04 docs(backlog): mark R01 as done and vendor SO101 URDF for Gazebo sim
    Claude-Session: https://claude.ai/code/session_01L9chZd9df6M5NSVxfXWeZN
    [base_motor_holder_so101_v1.stl, base_so101_v2.stl, motor_holder_so101_base_v1.stl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]
2026-09-04 feat(ros2): add robotic_arm_description package with SO101 xacro URDF
    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
    [base_motor_holder_so101_v1.stl, base_so101_v2.stl, motor_holder_so101_base_v1.stl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]
2026-09-04 feat(ros2): install meshes/urdf on build and save RViz display config
    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
2026-09-04 feat(ros2): add ros2_control + gazebo_ros2_control plugin, control the arm in Gazebo
    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
    [robotic_arm.urdf.xacro, robotic_arm_controllers.yaml, robotic_arm_gazebo.xacro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]
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2026-09-05 docs(backlog): add R04 task for servo backlash mitigation
    Claude-Session: https://claude.ai/code/session_01DdP4U8PTVn7GKCJnQXwBDh
2026-09-16 docs(backlog): mark E03 as done, no level shifter needed between ESP32 and servo driver
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2026-09-18 feat(moveit): add MoveIt2 config package for robotic_arm
    Planning and execution verified end-to-end in Gazebo simulation for
    both the arm and gripper planning groups via RViz MotionPlanning.
    [joint_limits.yaml]
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2026-09-19 docs(backlog): add R08 task, log R07 MoveIt2 API progress and pending gripper-limit bug
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2026-09-25 feat(controller): add ros2_control hardware interface skeleton for real arm
    [robotic_arm.urdf.xacro, robotic_arm_ros2_control.xacro]
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2026-09-25 fix(description): remove duplicate gazebo hardware block and fix real plugin name
    [robotic_arm_ros2_control.xacro]
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2026-10-09 docs(E03): verify ESP32-driver wiring (TX-TX, RX-RX, jumper A) and fix crossed wiring note
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2026-10-09 fix(firmware): answer M frames within one control cycle and log servo feedback
2026-10-09 docs(E06): log first arm test with M round trip and latency fix
2026-10-10 docs(E06): log convergence test, SYNC_READ timeout bug and wrist_roll calibration issue
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2026-10-10 fix(description): keep joint limits inside the measured physical range
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2026-10-10 fix(servo-tools): home to the calibrated zero and calibrate against the URDF zero pose
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2026-10-10 fix(controller): run controller_manager at 50 Hz
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2026-10-10 fix(moveit): plan task_server motions within the servo speed limit
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2026-10-23 feat(controller): send URDF limits in S and wait for its reply
    syncWithArm() now pauses and flushes after the probes, sends S with the
    URDF joint limits from info_.limits as param_init and waits up to 200 ms
    for the reply: M loads states and commands, E (01 panel in CTL, 20
    servos not answering, 21 invalid limits) or a timeout fail on_activate
    with a clear message. send_m.py prints the E reply codes.
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
